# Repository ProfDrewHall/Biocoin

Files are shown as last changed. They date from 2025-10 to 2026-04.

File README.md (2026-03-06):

# Biocoin Platform

Biocoin is a modular wearable electrochemical sensing platform that integrates custom electronics, embedded firmware, and host-side software for multi-analyte detection in biofluids such as sweat and interstitial fluid.

Developed by the [BioEE Group](https://bioee.ucsd.edu) at the University of California, San Diego, Biocoin combines multimodal biosignal acquisition with wireless communication, microfluidic interfacing, and open analytical tools.

---

## Repository Overview

This repository contains the design assets for the Biocoin platform across hardware, firmware, software, and mechanical fixtures.

| Folder | Description |
|:---|:---|
| [`firmware/`](firmware/) | PlatformIO-based firmware for the nRF52840 controller and AD5940 analog front-end, including BLE control and data streaming. |
| [`software/`](software/) | Python host software for BLE communication, technique execution, logging, and result export. |
| [`PCB/`](PCB/) | PCB schematics, layouts, Gerbers, assembly files, and shared component libraries. |
| [`fixtures/`](fixtures/) | Mechanical design assets, fabrication exports, and fixture models for assembly and validation. |

---

## Architecture

The Biocoin system is organized as:

```text
Host software (Python CLI/package in software/)
  -> BLE GATT protocol
  -> nRF52840 firmware (firmware/)
     - SensorManager and technique implementations
     - AD5940 driver and board support
     - BLE, power, battery, and storage modules
  -> AD5940 analog front-end
  -> Electrochemical cell and integrated sensors
```

The current firmware structure is consistent with a FreeRTOS-based design using `SensorManager`, technique-specific sensor modules, and BLE streaming tasks.

---

## Supported Techniques

| Technique | Description | Output |
|:---|:---|:---|
| **CA** | Chronoamperometry | Current vs. time |
| **CV** | Cyclic Voltammetry | Current vs. voltage |
| **DPV** | Differential Pulse Voltammetry | Peak current vs. potential |
| **SWV** | Square-Wave Voltammetry | Differential current vs. potential |
| **IMP / EIS** | Impedance spectroscopy | Magnitude and phase |
| **OCP** | Open-circuit potential | WE potential vs. RE |
| **TEMP** | Temperature monitoring | Voltage-derived temperature data |
| **IONTOPH** | Iontophoretic stimulation | Current control and monitoring |

Each technique can be configured from the host and controlled over BLE. Data-producing techniques stream results back to the host software.

---

## Development Requirements

### Firmware

- [PlatformIO](https://platformio.org/) for build and flash workflows
- A supported nRF52840 board configuration for the Biocoin hardware
- Optional DFU tooling such as Nordic `nrfutil`

### Software

- Python 3.13 or newer
- Recommended: [`uv`](https://docs.astral.sh/uv/) for environment and dependency management
- Python dependencies defined in [`software/pyproject.toml`](software/pyproject.toml):
  - `bleak`
  - `colorama`
  - `numpy`

### Hardware and Mechanical

- Altium Designer or another tool capable of reviewing the PCB source/export files
- CAD software such as SolidWorks or FreeCAD for fixture review and export

---

## Typical Workflow

1. Build and flash the firmware in [`firmware/`](firmware/).
2. Use the Python tooling in [`software/`](software/) to connect over BLE.
3. Run a supported electrochemical technique and collect results.
4. Review or update board and fixture assets in [`PCB/`](PCB/) and [`fixtures/`](fixtures/).

---

## Example Directory Layout

```text
Biocoin/
|-- firmware/   # Embedded firmware, docs, scripts, and tests
|-- software/   # Python package, CLI runners, tests, logs, and results
|-- PCB/        # Board designs, Gerbers, assembly outputs, libraries
`-- fixtures/   # Mechanical assets and fabrication files
```

---

## Licensing

This repository contains both software and hardware design assets. Unless otherwise noted:

- [`firmware/`](firmware/) and [`software/`](software/) are provided under the MIT License.
- [`PCB/`](PCB/) and [`fixtures/`](fixtures/) are provided under the CERN-OHL-W v2.0 license.

See the top-level [`LICENSE`](LICENSE) file for the repository-level license notice.

---

## Authors and Maintainers

**BioEE Group, University of California, San Diego**

Principal Investigator: [Prof. Drew A. Hall](https://bioee.ucsd.edu)

Contributors:

- Risab Sankar
- Tyler Hack
- Members of the BioEE Group (UCSD ECE)

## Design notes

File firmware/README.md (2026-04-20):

# Biocoin Firmware

Firmware for the Biocoin wearable electrochemical platform.
This code runs on an nRF52840-based board and controls an Analog Devices AD5940 for multi-modal electrochemical sensing. It exposes a BLE interface for configuring techniques, starting/stopping tests, and streaming results to a host (Python app, mobile, etc.).

Current release: **v1.1.5**

> Techniques supported: **CA**, **CV**, **DPV**, **SWV**, **Impedance (EIS)**, **OCP**, **TEMP**, and **Iontophoresis**.

## v1.1.5 Highlights

- Improved BLE status reporting for malformed sensor control and parameter writes.
- Cleared stale error states after successful same-technique parameter updates.
- Made active-sensor cleanup failures preserve the active sensor and publish `ERROR` instead of masking failures as `NOT_RUNNING`.

---

## Features

- Modular sensor stack (`sensors/core` + `sensors/techniques`) with a common `Sensor` base class
- AD5940 HAL integration (clock/FIFO/LPDAC/LPAMP/DFT/sequencer, RTIA calibration) - based on ADI code
- Low-power operation with wakeup timer & sleep
- BLE data streaming and status updates
- Typed parameter blocks with bounds checks where applicable
- Lock-free byte streaming of results (float payloads)

---

## Getting Started

### Prerequisites
- [PlatformIO](https://platformio.org/) (VS Code extension or CLI)
- Note: If you are building on a linux-based platform, you'll need to install the udev rules (https://docs.platformio.org/en/latest/core/installation/udev-rules.html)
- Board: Biocoin board based on nRF52840
- Tooling for DFU (optional): Nordic `nrfutil`

### Build
From VS Code (PlatformIO) or CLI:
```bash
pio run
```

Note: `DEBUG_MODE` builds briefly block at startup while waiting for a USB serial connection to attach. The current timeout is about 2 seconds; after that, startup continues normally even if no serial monitor is connected.

Optional pre-push hook (runs sanity checks + mode smoke checks, builds `debug` + `release`, and copies artifacts to `build/<env>/`):
```bash
git config core.hooksPath .githooks
```

On Linux/macOS:
```bash
chmod +x .githooks/pre-push
```

On Windows (PowerShell), no `chmod` step is required.

### Flash
USB (default PlatformIO upload target):
```bash
pio run -t upload
```

DFU (example with `nrfutil`, adjust paths/softdevice/bootloader as needed):
```bash
# Example only - adapt to your bootloader/DFU flow
nrfutil dfu usb-serial -pkg firmware_dfu.zip -p <COM_PORT> -b 115200
```

---

## Repository Structure (high level)

```
src/
  main.cpp
  HWConfig/
    constants.h         # Aggregates build checks + config + pins
    build_checks.h      # Compile-time environment validation
    config.h            # Firmware/version/runtime constants
    pins.h              # Board pin assignments
  variants/biocoin/
    variant.h
    variant.cpp
  sensors/
    core/
      sensor.{h,cpp}
      sensor_manager.{h,cpp}
      datamover_task.{h,cpp}
    techniques/
      sequence_constants.h
      ca/echem_ca.{h,cpp}
      cv/echem_cv.{h,cpp}
      dpv/echem_dpv.{h,cpp}
      swv/echem_swv.{h,cpp}
      imp/echem_imp.{h,cpp}
      ocp/echem_ocp.{h,cpp}
      temp/echem_temp.{h,cpp}
      iontophoresis/iontophoresis.{h,cpp}
  bluetooth/
    bluetooth.{h,cpp}
    gatt.{h,cpp}
    transmitdata_task.h
    transmitdata_task.cpp
  battery/
    battery.{h,cpp}
    battery_task.{h,cpp}
  power/
    power.{h,cpp}
    led_task.{h,cpp}
  storage/
    storage.{h,cpp}
  drivers/
    ad5940_hal.{h,cpp}
    ad5940_helper.{h,cpp}
  util/
    debug_log.h
    task_sync.h
    util.{h,cpp}
```

---

## Architecture

All techniques inherit from `sensor::Sensor` and (for streaming) use `SensorQueue<T>` to push typed samples. `SensorManager` owns the active technique and mediates:

- `loadParameters(uint8_t* data, uint16_t len)`
- `start()` / `stop()`
- `ISR()` (invoked via AFE interrupt / data mover task)

**Data streaming:** techniques push `float` samples; the BLE TX pipeline sends a raw byte vector (little-endian floats) produced by `SensorQueue<T>::popBytes()`.

---

## SDK

This project now uses a repo-local PlatformIO variant in `src/variants/biocoin` (configured in `platformio.ini`) so board pin mapping/build settings are version-controlled with firmware source.
No manual edits to PlatformIO package files are required.
For lowest-power operation, SDK-level `WInterrupts` changes are still required (see `SDK Modifications/WInterrupts-port.c` and `SDK Modifications/WInterrupts-port.h`).

---

## Documentation

- `docs/README.md` - docs index and navigation
- `docs/BLE_PROTOCOL.md` - protocol and payload reference
- `docs/BUILD_FLASH.md` - build/flash environment notes
- `docs/BATTERY_CALIBRATION.md` - BLE logging + fit workflow for battery percent calibration constants
- `docs/POWER.md` - low-power behavior and SDK patch requirements
- `docs/RELEASE_CHECKLIST.md` - release prep checklist
- `test/README.md` - targeted parser/state transition test plan and vectors

---

## BLE Protocol (summary)

- A **Parameters** characteristic accepts a binary payload:
  - Byte `0`: `sensor::SensorType` (technique selector)
  - Bytes `1..N`: packed parameter struct for that technique (see below)
- A **Control** characteristic accepts a command (`START` / `STOP`)
- A **Status** characteristic reports `TestState` (`NOT_RUNNING`, `RUNNING`, `ERROR`, etc.)
- A **Data** characteristic streams measurement results as raw bytes (floats)
- TX transport detail: outgoing BLE data uses a bounded FreeRTOS stream buffer. If producers outrun BLE notify throughput, excess bytes are dropped and logged.

> UUIDs/handles are defined in the BLE layer (see `src/bluetooth/gatt.*`). Host apps should send the correct packed struct for the selected technique.

---

## Parameter Payloads (packed)

Below are the **packed** C layouts (host must match layout, types, and units). Each write to the Parameters characteristic must begin with the technique selector byte (`sensor::SensorType`) followed by the corresponding struct bytes.

### Chronoamperometry (CA)
```c++
struct CA_PARAMETERS {
  float  samplingInterval;    // [s]
  float  processingInterval;  // [s]
  float  maxCurrent;          // [uA] range hint
  float  pulsePotential;      // [mV] WE-RE pulse amplitude
  uint8_t channel;            // 0..3 (board mux)
} __attribute__((packed));
```

### Cyclic Voltammetry (CV)
```c++
struct CV_PARAMETERS {
  float  processingInterval;  // [s]
  float  maxCurrent;          // [uA] range hint
  float  Estart;              // [mV]
  float  Evertex1;            // [mV]
  float  Evertex2;            // [mV]
  float  Estep;               // [mV] step between DAC codes
  float  pulseWidth;          // [ms]
  uint8_t channel;            // 0..3
} __attribute__((packed));
```

### Differential Pulse Voltammetry (DPV)
```c++
struct DPV_PARAMETERS {
  float  processingInterval;  // [s]
  float  maxCurrent;          // [uA] range hint
  float  Estart;              // [mV]
  float  Estop;               // [mV]
  float  Epulse;              // [mV] pulse height
  float  Estep;               // [mV] ramp step
  float  pulseWidth;          // [ms]
  float  pulsePeriod;         // [ms]
  uint8_t channel;            // 0..3
} __attribute__((packed));
```

### Square Wave Voltammetry (SWV)
```c++
struct SWV_PARAMETERS {
  float  processingInterval;  // [s]
  float  maxCurrent;          // [uA] range hint
  float  Estart;              // [mV]
  float  Estop;               // [mV]
  float  Eamplitude;          // [mV] square-wave amplitude
  float  Estep;               // [mV] staircase step
  float  pulsePeriod;         // [ms]
  uint8_t channel;            // 0..3
} __attribute__((packed));
```

### Impedance / EIS (IMP)
```c++
struct IMP_PARAMETERS {
  float  samplingInterval;    // [s]
  float  processingInterval;  // [s]
  uint8_t IMP_4wire;          // 1=4-wire, 0=2-wire
  uint8_t AC_coupled;         // 1=AC, 0=DC
  float  maxCurrent;          // [uA] range hint
  float  Eac;                 // [mV] AC excitation
  float  frequency;           // [Hz]
} __attribute__((packed));
```

### Open Circuit Potential (OCP)
```c++
struct OCP_PARAMETERS {
  float  samplingInterval;    // [s]
  float  processingInterval;  // [s]
  uint8_t channel;            // board/AFE mux (see note)
} __attribute__((packed));
```

### Temperature Monitor (TEMP)
```c++
struct TEMP_PARAMETERS {
  float  samplingInterval;    // [s]
  float  processingInterval;  // [s]
  uint8_t channel;            // ADCMUXP_* selection (board dependent)
} __attribute__((packed));
```

### Iontophoresis
```c++
struct IONTOPHORESIS_PARAMETERS {
  float  samplingInterval;    // [s] monitor interval
  float  stimCurrent;         // [uA] commanded
  float  maxCurrent;          // [uA] safety threshold
} __attribute__((packed));
```

> **Channels:** `channel` maps to board-level MUX/AD5940 inputs (e.g., `ADCMUXP_*`). Keep host-side enums in sync with the firmware build for your hardware variant.

---

## Running a Technique (host flow)

1. **Select technique**: Write `SensorType` + packed struct to the **Parameters** characteristic.
2. **Start**: Write `START` to **Control**.
3. **Stream**: Subscribe to **Data** notifications (float samples as little-endian bytes).
4. **Stop**: Write `STOP` to **Control**.
5. **Status**: Read/subscribe to **Status** (`NOT_RUNNING`, `RUNNING`, `ERROR`, etc.).

---

## Implementation Notes

- AD5940 reference voltage should match your measured value (see configs in each technique).
- RTIA selection/auto-cal: Some techniques call `AD5940_CalibrateRTIA` unless external RTIA is forced.
- Power: Firmware disables SPI / enters sleep when possible to reduce current.
- Data types:
  - **Current** streams are in **µA** (computed from ADC code, PGA gain, Vref, and RTIA).
  - **Voltage** streams (e.g., OCP, TEMP) are in **mV**.
- Byte order: little-endian for all streamed floats.

---

## Troubleshooting

- **No data**: Ensure `processingInterval >= samplingInterval` (where applicable).
- **Invalid parameters**: Firmware replies via **Status** (`INVALID_PARAMETERS`) if struct size or values are off.
- **Out of range currents**: Pick appropriate `maxCurrent` so the code selects a safe RTIA/gain.
- **MTU**: For larger throughput, request higher ATT MTU on the central (typical 185-247+ depending on OS).

---

## ToDo List
Near term:
- Implement the current range for CA
- Implement advanced parameters
- Add comments / file headers / Readme.MD
- Add static_assert to check config constants
- Cleanup / refactor / reorganize code

Long term:
- Add other techniques: EIS, NPV, LSV, etc.
- Add CRC to parameters for BLE comm?
- Add a serial # to the BLE characteristics

---

## License

MIT

---

## Authors

**Drew A. Hall**
University of California, San Diego
Contact: drewhall@ucsd.edu

**Risab Sankar**
University of California, San Diego
Contact: rsankar@ucsd.edu

**Tyler Hack**
University of California, San Diego
Contact: thack@ucsd.edu

---

### Acknowledgments
Thanks to the BioEE group at UC San Diego and collaborators for contributions and testing.

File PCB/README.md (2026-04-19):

# PCB Design Files

This directory contains the PCB design deliverables for the BioCoin hardware, including source design files, fabrication outputs, assembly files, and shared Altium libraries.

## Folder Overview

### `Biocoin/`

PCB files for the BioCoin board.

- `design/`: Altium project files, PCB layout, schematics, harness files, and output job definitions
- `gerber/`: fabrication outputs for board manufacturing
- `assembly/`: bill of materials and pick-and-place files for assembly
- `Schematic.PDF`: exported schematic reference

Notable files:

- `design/Biocoin_v1.3.PrjPcb`
- `design/Biocoin_v1.3.PcbDoc`
- `assembly/BOM_Final_Biocoin_v1.3_AVDD=3.0V.xlsx`
- `assembly/BOM_Final_Biocoin_v1.3_AVDD=3.6V.xlsx`
- `assembly/Pick_and_Place_Assembly_Biocoin_v1.3.txt`

### `Docking Station/`

PCB files for the BioCoin docking station / motherboard.

- `design/`: Altium project files, PCB layout, schematics, and output job definitions
- `gerber/`: fabrication outputs for board manufacturing
- `assembly/`: bill of materials and pick-and-place files for assembly
- `Schematic.PDF`: exported schematic reference

Notable files:

- `design/Biocoin_Motherboard_v1.0.PrjPcb`
- `design/Biocoin_Motherboard.PcbDoc`
- `assembly/BOM_Final_DockingStation_v1.0.xlsx`
- `assembly/Pick_and_Place_Assembly_DockingStation_v1.0.txt`

### `Shared Libraries/`

Reusable Altium schematic and PCB libraries shared across the designs in this folder.

- `Modules.SchLib`
- `Modules.PcbLib`
- `Schlib.SchLib`
- `PcbLib.PcbLib`

## Manufacturing And Assembly Notes

For each board:

- Use the files in `gerber/` for PCB fabrication
- Use the files in `assembly/` for population and placement
- Use the `design/` folder if you need to open or modify the board in Altium Designer
- Use `Schematic.PDF` for quick review without opening the design tools

## Click-To-Order Links

### Biocoin

- [Order 10 sets](https://pcbminions.com/product/product_1773404171-10sets)
- [Order 100 sets](https://pcbminions.com/product/product_1773404171-100sets)

### Docking Station

- [Order 10 sets](https://pcbminions.com/product/product_1773677769-10sets)
- [Order 100 sets](https://pcbminions.com/product/product_1773677769-100sets)

## Tooling

These files are in Altium Designer format (`.PrjPcb`, `.PcbDoc`, `.SchDoc`, `.OutJob`, `.SchLib`, `.PcbLib`).

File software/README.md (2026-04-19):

# Biocoin Device Software

This repository contains Python code to interface with the Biocoin hardware platform over BLE.
It supports configuration and execution of all currently implemented techniques:

- Chronoamperometry (CA)
- Cyclic Voltammetry (CV)
- Differential Pulse Voltammetry (DPV)
- Square-Wave Voltammetry (SWV)
- Impedance (IMP)
- Open-Circuit Potential (OCP)
- Temperature Monitoring (TEMP)
- Iontophoresis (IONTOPH)

The software is organized as:

- a reusable backend library in `src/biocoin/`
- a Streamlit GUI package in `src/biocoin_gui/`
- standalone technique runner scripts in `src/run_*.py`

---

## Setup

The software requires Python 3.13 or newer. The backend uses Python 3.13 generic class syntax, so Streamlit must also run from a Python 3.13+ environment.

### 1. Clone the repository

```bash
git clone https://github.com/ProfDrewHall/Biocoin.git
cd Biocoin/software
```

### 2. Install Python 3.13

macOS with Homebrew:

```bash
brew install python@3.13
```

Confirm the installed version:

```bash
python3.13 --version
```

### 3. Create and activate a virtual environment

From the `software` directory:

```bash
python3.13 -m venv .venv
source .venv/bin/activate
python -m pip install --upgrade pip
```

After activation, `python --version` should report Python 3.13 or newer.

### 4. Install the package and dependencies

```bash
python -m pip install -e .
```

### 5. Run a technique script

Example:

```bash
python src/run_CA.py --help
```

### 6. Run the Streamlit GUI

```bash
python -m streamlit run src/biocoin_gui/app.py
```

Use `python -m streamlit` instead of `streamlit` so the GUI runs with the active Python 3.13 virtual environment.

If you are using `uv`, run:

```bash
uv run --python 3.13 streamlit run src/biocoin_gui/app.py
```

### Optional: Use `uv`

If you prefer `uv`, install it first:

```bash
brew install uv
```

Then run the GUI with Python 3.13:

```bash
uv run --python 3.13 streamlit run src/biocoin_gui/app.py
```

---

## Technique Runner Scripts

Each technique has a dedicated CLI script that exposes its parameters:

```bash
python src/run_CA.py --help
python src/run_CV.py --help
python src/run_DPV.py --help
python src/run_SWV.py --help
python src/run_IMP.py --help
python src/run_OCP.py --help
python src/run_TEMP.py --help
python src/run_IONTO.py --help
```

Typical output CSV paths default to `./results/*_output.csv` for data-producing techniques.

---

## Technique Lifecycle Contract

General flow:

1. `await technique.configure(...)`
2. `data = await technique.run(...)`
3. Consume `data` as a NumPy array

Returned shape expectations:

- Timed techniques (`CA`, `OCP`, `TEMP`, `IMP`) can return a variable number of samples based on BLE/runtime timing.
- Sweep techniques (`CV`, `DPV`, `SWV`) are expected to return deterministic point counts from their configured vectors.
- `Iontophoresis` does not stream samples and returns an empty `(0, 2)` array.

---

## Directory Layout

```text
src/
|-- run_CA.py
|-- run_CV.py
|-- run_DPV.py
|-- run_SWV.py
|-- run_IMP.py
|-- run_OCP.py
|-- run_TEMP.py
|-- run_IONTO.py
|-- biocoin/
|   |-- __init__.py
|   |-- device.py
|   |-- errors.py
|   |-- techniques/
|   |   |-- __init__.py
|   |   |-- base_technique.py
|   |   |-- ca.py
|   |   |-- cv.py
|   |   |-- dpv.py
|   |   |-- swv.py
|   |   |-- impedance.py
|   |   |-- ocp.py
|   |   |-- temp.py
|   |   |-- iontophoresis.py
|   |   |-- pulse_voltammetry.py
|   |   `-- validation.py
|   `-- utils/
|       `-- ble_util.py
|-- biocoin_gui/
|   |-- __init__.py
|   |-- app.py
|   |-- runtime.py
|   `-- pages/
|       |-- __init__.py
|       |-- ca.py
|       |-- cv.py
|       |-- dpv.py
|       |-- imp.py
|       |-- ip.py
|       |-- ocp.py
|       |-- swv.py
|       `-- temp.py
`-- utils/
    `-- logging_util.py
```

---

## License

MIT License

---

## Authors

**Drew A. Hall**
University of California, San Diego
Contact: drewhall@ucsd.edu

**Risab Sankar**
University of California, San Diego
Contact: rsankar@ucsd.edu

**Tyler Hack**
University of California, San Diego
Contact: thack@ucsd.edu

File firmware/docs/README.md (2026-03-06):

# Documentation Index

- `BLE_PROTOCOL.md`: BLE characteristics, command framing, and payload notes.
- `BUILD_FLASH.md`: Build/flash notes and environment assumptions.
- `BATTERY_CALIBRATION.md`: BLE logging, curve fitting, and config update workflow for battery percent calibration.
- `CA_TECHNIQUE.md`: CA-specific parameter constraints, timing behavior, and ENDSEQ handling.
- `CV_TECHNIQUE.md`: CV parameter constraints, wakeup timing guards, and ENDSEQ behavior.
- `DPV_TECHNIQUE.md`: DPV parameter constraints, pulse timing guards, and ENDSEQ behavior.
- `SWV_TECHNIQUE.md`: SWV parameter constraints, timing guards, and ENDSEQ behavior.
- `OCP_TECHNIQUE.md`: OCP channel/rate constraints, wakeup guards, and ENDSEQ behavior.
- `TEMP_TECHNIQUE.md`: Temperature channel/rate constraints, wakeup guards, and ENDSEQ behavior.
- `IMP_TECHNIQUE.md`: Impedance parameter constraints, wakeup guards, and ISR behavior.
- `IONTOPHORESIS_TECHNIQUE.md`: Iontophoresis parameter and runtime safety behavior.
- `CONTRIBUTING.md`: Coding, naming, and documentation conventions for firmware changes.
- `POWER.md`: Low-power behavior and required SDK `WInterrupts` patch context.
- `RELEASE_CHECKLIST.md`: Pre-release checklist for firmware updates.

## Known Issues / Limitations

- Lowest-power operation still depends on SDK-level `WInterrupts` modifications (`SDK Modifications/WInterrupts-port.c` and `SDK Modifications/WInterrupts-port.h`).
- Build warning gating excludes vendor code warnings (for example, `src/drivers/ad5940.c`); project code warnings are expected to stay clean.
- BLE TX uses a bounded stream buffer; if producer throughput exceeds notify throughput, some bytes may be dropped (logged as warnings).

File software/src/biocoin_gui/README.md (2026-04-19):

# Biocoin GUI

Streamlit-based graphical interface for the Biocoin control software.

## Layout

- `app.py`: Main Streamlit entrypoint and navigation setup.
- `runtime.py`: Shared GUI helpers for session state, background experiment execution, and exports.
- `pages/`: Technique-specific experiment pages.

## Running The GUI

From the repository root:

```bash
uv run --python 3.13 streamlit run src/biocoin_gui/app.py
```

## TODO

- Periodically check that the device connection is still active and update the GUI state when it drops.
- Block other experiments from starting until the current experiment is complete.

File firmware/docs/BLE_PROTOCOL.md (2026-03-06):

# BLE Protocol Notes

## Characteristics

- Parameters: binary payload (`SensorType` + packed parameter struct bytes).
- Control: single-byte command (`START`, `STOP`).
- Status: single-byte `TestState`.
- Data: raw little-endian float stream.

### Debug-only Characteristics (`DEBUG_MODE` builds only)

- Debug Battery Voltage: UUID `00001526-1212-EFDE-1523-785FEABC93AA`
  - Properties: `READ`, `NOTIFY`
  - Payload: 2-byte unsigned little-endian battery voltage in millivolts (`uint16`)
  - Example: payload `0xD2 0x0E` => `3794 mV`

## Payload Compatibility Rules

- Control writes must be exactly 1 byte.
- Parameters writes must be between 1 byte and the current BLE payload max (`MTU - ATT header`).
- Device name writes must be between 1 byte and `BLE_GAP_DEVNAME_MAX_LEN - 1`.
- Invalid payload length or null payload is ignored by firmware and logged as a warning.
- Host implementations should treat ignored writes as protocol errors and retry only with corrected payloads.

## TX Path Behavior

- Outgoing data is buffered in a bounded FreeRTOS stream buffer.
- Data is chunked to current negotiated MTU payload size.
- If producers outrun notify throughput, bytes can be dropped and a warning is logged.

## Host Guidance

- Always subscribe to Data before issuing `START`.
- Validate returned status transitions when changing techniques.
- Keep host-side struct packing and enum values in lock-step with firmware.

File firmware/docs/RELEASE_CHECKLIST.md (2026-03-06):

# Release Checklist

## Minimum Acceptance (must pass)

- [ ] `.githooks/pre-push` passes locally (sanity checks + mode smoke checks + `debug`/`release` builds + artifact copy).
- [ ] BLE smoke path passes at least once per release build: connect -> write parameters -> `START` -> data notify -> `STOP`.
- [ ] Battery reporting and device-name write/read behavior verified on hardware.
- [ ] Sleep/idle spot-check confirms no obvious high-power regression.

## Versioning and Notes

- [ ] Update firmware version in `src/HWConfig/config.h`.
- [ ] Update `REVISION_HISTORY.md` with release title/date and key changes.
- [ ] Verify `README.md` reflects current technique support and file layout.
- [ ] Verify version string is consistent across `README.md`, `REVISION_HISTORY.md`, and the intended git tag (for example, `v1.1.0`).

## Build and Validation

- [ ] Run `sh scripts/sanity_checks.sh`.
- [ ] Run `sh scripts/smoke_sensor_modes.sh`.
- [ ] Build firmware (`pio run -e debug` and `pio run -e release`).
- [ ] Flash and smoke test BLE connect/start/stop/data path.
- [ ] Verify battery reporting and device-name update behavior.
- [ ] Confirm no unintended high-power regressions.

## Repository Hygiene

- [ ] Ensure no temporary logs/artifacts are tracked.
- [ ] Confirm renamed/moved files are reflected in docs.
- [ ] Review release delta for unexpected files: `git diff --stat <last-tag>..HEAD`.
- [ ] Review full release commit list: `git log --oneline <last-tag>..HEAD`.
- [ ] Tag release commit after validation.

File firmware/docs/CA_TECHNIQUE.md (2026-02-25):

# Chronoamperometry (CA) Notes

This note captures CA-specific runtime constraints and behavior so the same rules can be applied to other electrochemistry techniques.

## Host Parameter Constraints

- Payload layout (`CAParameterPayload`) is fixed-size packed data (`17` bytes).
- `samplingInterval` and `processingInterval` must be finite and greater than `0`.
- `processingInterval` must be greater than or equal to `samplingInterval`.
- `channel` must be in range `[0, 3]`.
- `pulsePotential` must remain within bias limits derived from current `Vzero`:
  - `minBias = AD5940_MIN_DAC_OUTPUT - Vzero`
  - `maxBias = AD5940_MAX_DAC_OUTPUT - Vzero`

## FIFO Threshold Behavior

- FIFO threshold is computed as:
  - `round(processingInterval / samplingInterval)`
- Threshold is clamped to:
  - minimum: `kCAMinFifoThreshold`
  - maximum: `kCAMaxFifoThreshold`

## Wakeup Timer Behavior

- CA builds wakeup timer config from measured `LFOSCFreq` and configured sampling interval.
- Wake period uses:
  - `kCAWuptSleepTicks`
  - `kCAWuptWakeSubtractTicks`
- Start fails with cleanup if computed wake ticks are non-finite or too small.

## ENDSEQ Handling

- ISR drains FIFO on both `DATAFIFOTHRESH` and `ENDSEQ`.
- On `ENDSEQ`, CA stops the technique and publishes:
  - `NOT_RUNNING` on successful stop
  - `ERROR` if stop fails

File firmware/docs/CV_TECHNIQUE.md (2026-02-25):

# Cyclic Voltammetry (CV) Notes

## Host Parameter Constraints

- Payload layout (`CVParameterPayload`) is fixed-size packed data (`29` bytes).
- `processingInterval` and `pulseWidth` must be finite and greater than `0`.
- `Estep` must be non-zero.
- `channel` must be in range `[0, 3]`.
- Voltage points (`Estart`, `Evertex1`, `Evertex2`) must remain inside DAC headroom derived from `VzeroStart`.

## FIFO Threshold Behavior

- FIFO threshold is computed as `round(processingInterval * 1000 / pulseWidth)`.
- Threshold is clamped to `[1, 1023]`.

## Wakeup Timer Behavior

- Wakeup timer settings are validated before start.
- Start fails if computed wake/sleep ticks are non-finite or too small after timing offsets.

## Runtime Behavior

- Start has centralized failure cleanup (`cleanupStartFailure`) to guarantee SPI/peripheral shutdown.
- ISR drains FIFO for both `DATAFIFOTHRESH` and `ENDSEQ` events.
- On `ENDSEQ`, CV stops and publishes `NOT_RUNNING` (or `ERROR` if stop fails).

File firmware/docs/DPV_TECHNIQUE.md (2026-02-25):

# Differential Pulse Voltammetry (DPV) Notes

## Host Parameter Constraints

- Payload layout (`DPVParameterPayload`) is fixed-size packed data (`33` bytes).
- `processingInterval`, `pulseWidth`, and `pulsePeriod` must be finite and greater than `0`.
- `pulsePeriod` must be greater than or equal to `pulseWidth`.
- `Estep` must be non-zero.
- `channel` must be in range `[0, 3]`.
- Voltage points (`Estart`, `Estop`, `Epulse`) must remain inside DAC headroom derived from `VzeroStart`.

## FIFO Threshold Behavior

- FIFO threshold is computed as `round(processingInterval * 1000 / pulseWidth)`.
- Threshold is clamped to `[1, 1023]`.

## Wakeup Timer Behavior

- High/low pulse timing ticks are validated before start.
- Start fails if any computed wakeup ticks are non-finite or too small after timing offsets.

## Runtime Behavior

- Start has centralized failure cleanup (`cleanupStartFailure`) to guarantee SPI/peripheral shutdown.
- ISR drains FIFO for both `DATAFIFOTHRESH` and `ENDSEQ` events.
- On `ENDSEQ`, DPV stops and publishes `NOT_RUNNING` (or `ERROR` if stop fails).

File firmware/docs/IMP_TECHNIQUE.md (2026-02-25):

# Impedance (IMP/EIS) Notes

## Host Parameter Constraints

- Payload layout (`IMPParameterPayload`) is fixed-size packed data (`22` bytes).
- `samplingInterval`, `processingInterval`, `frequency`, and `Eac` must be finite and greater than `0`.
- `processingInterval` must be greater than or equal to `samplingInterval`.
- Boolean flag fields (`IMP_4wire`, `AC_coupled`) must be `0` or `1`.

## FIFO Threshold Behavior

- FIFO threshold is computed from interval ratio and rounded down to a multiple of `4` samples.
- Minimum threshold is `4`.

## Wakeup Timer Behavior

- Wakeup ticks are validated before start.
- Start fails if ticks are non-finite or too small for configured wake/sleep offsets.

## Runtime Behavior

- Start has centralized failure cleanup (`cleanupStartFailure`) to guarantee SPI/peripheral shutdown.
- ISR drains FIFO for both `DATAFIFOTHRESH` and `ENDSEQ` events.
- On `ENDSEQ`, IMP stops and publishes `NOT_RUNNING` (or `ERROR` if stop fails).

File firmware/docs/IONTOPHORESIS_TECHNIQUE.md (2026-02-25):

# Iontophoresis Notes

## Host Parameter Constraints

- Payload layout (`IontophoresisParameterPayload`) is fixed-size packed data (`12` bytes).
- `samplingInterval` and `maxCurrent` must be finite and greater than `0`.
- `stimCurrent` must be finite, greater than or equal to `0`, and less than or equal to `maxCurrent`.

## Runtime Behavior

- Start has centralized failure cleanup (`cleanupStartFailure`) to guarantee SPI/peripheral shutdown.
- Stimulation safety is enforced in the monitoring task by comparing measured current against `maxCurrent`.
- On safety overcurrent, iontophoresis stops and publishes `CURRENT_LIMIT_EXCEEDED`.

## Timing Note

- This technique does not use AD5940 wakeup timer sequencing for sample cadence.
- Sampling cadence is controlled by the FreeRTOS monitoring task delay.

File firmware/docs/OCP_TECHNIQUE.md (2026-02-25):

# Open Circuit Potential (OCP) Notes

## Host Parameter Constraints

- Payload layout (`OCPParameterPayload`) is fixed-size packed data (`9` bytes).
- `samplingInterval` and `processingInterval` must be finite and greater than `0`.
- `processingInterval` must be greater than or equal to `samplingInterval`.
- `channel` must be one of the allowed OCP mux channels.

## FIFO Threshold Behavior

- FIFO threshold is computed as `round(processingInterval / samplingInterval)`.
- Threshold is clamped to `[1, 1023]`.

## Wakeup Timer Behavior

- Wakeup ticks are validated before start.
- Start fails if ticks are non-finite or too small for configured wake/sleep offsets.

## Runtime Behavior

- Start has centralized failure cleanup (`cleanupStartFailure`) to guarantee SPI/peripheral shutdown.
- ISR drains FIFO for both `DATAFIFOTHRESH` and `ENDSEQ` events.
- On `ENDSEQ`, OCP stops and publishes `NOT_RUNNING` (or `ERROR` if stop fails).

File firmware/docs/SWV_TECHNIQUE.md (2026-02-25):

# Square Wave Voltammetry (SWV) Notes

## Host Parameter Constraints

- Payload layout (`SWVParameterPayload`) is fixed-size packed data (`29` bytes).
- `processingInterval` and `pulsePeriod` must be finite and greater than `0`.
- `Estep` must be non-zero.
- `channel` must be in range `[0, 3]`.
- Voltage points (`Estart`, `Estop`, `Eamplitude`) must remain inside DAC headroom derived from `VzeroStart`.

## FIFO Threshold Behavior

- FIFO threshold is computed as `round(processingInterval * 1000 / (pulsePeriod / 2))`.
- Threshold is clamped to `[1, 1023]`.

## Wakeup Timer Behavior

- Sample-delay and pulse-width timing ticks are validated before start.
- Start fails if computed ticks are non-finite or too small after timing offsets.

## Runtime Behavior

- Start has centralized failure cleanup (`cleanupStartFailure`) to guarantee SPI/peripheral shutdown.
- ISR drains FIFO for both `DATAFIFOTHRESH` and `ENDSEQ` events.
- On `ENDSEQ`, SWV stops and publishes `NOT_RUNNING` (or `ERROR` if stop fails).

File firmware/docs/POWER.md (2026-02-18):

# Power Notes

## Runtime Strategy

- Peripheral blocks are enabled only when needed for active measurements.
- Multiple input GPIOs are explicitly disconnected to minimize leakage.
- BLE TX uses bounded buffering to avoid unbounded memory growth.

## SDK Patch Requirement

- Lowest-power operation still requires SDK-level `WInterrupts` modifications.
- See:
  - `SDK Modifications/WInterrupts-port.c`
  - `SDK Modifications/WInterrupts-port.h`

## Validation Suggestions

- Measure current in idle advertising, connected idle, and active measurement modes.
- Re-check power after any pin-map or interrupt-path change.

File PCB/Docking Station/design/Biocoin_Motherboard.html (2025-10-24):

Reporting Options

# File in Newer Format

Date | : | 7/17/2022
Time | : | 7:33:55 PM
Project name | : | C:\Users\TEMP\Documents\PCB Projects\Biocoin_Motherboard\Biocoin_Motherboard.PrjPcb
Schematic documents | : | DIGITAL_DATA.SchDoc

Version | Warning
22.3.0 | Custom diff pair suffixes are not supported in this version.

These files were generated in a later version of Altium Designer. Be aware that some data may have been added through functionality not available in your current version and will therefore not be available to you.

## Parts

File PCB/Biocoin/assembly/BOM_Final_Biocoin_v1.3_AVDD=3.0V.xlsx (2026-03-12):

Manufacturer_Part_Number | Description | Designator | Quantity on PCB | Value | Do Not Install | Unit Price ($USD) (@ Quantity 10x) | Unit Price ($USD) (@ Quantity 100x) | Supplier
C0603X5R1E473K030BB | Multilayer Chip Capacitor 0201 | C38 | 1 | 47nF |  | 0.039 | 0.0227 | Digikey
C0603X5R1E104K030BB | Multilayer Chip Capacitor 0201 | C37 | 1 | 100nF |  | 0.043 | 0.0253 | Digikey
C0201C104K9PAC7867 | Multilayer Chip Capacitor 0201 | C3, C4, C6, C12, C13, C17, C21, C27, C32, C33, C34, CLPF1 | 12 | 100nF |  | 0.045 | 0.0263 | Digikey
C0603X5R1A474M030BC | Multilayer Chip Capacitor 0201 | C1, C7, C10, C14 | 4 | 470nF |  | 0.102 | 0.063 | Digikey
0201X105K6R3CT | Multilayer Chip Capacitor 0201 | C20, C29, C39 | 3 | 1uF |  | 0.105 | 0.105 | Digikey
GRM035R60J475ME15D | Multilayer Chip Capacitor 0201 | C2, C5,C8, C15, C18, C25, C26, C28, C30 | 9 | 4.7uF |  | 0.112 | 0.0701 | Digikey
C0402C333J4RACAUTO | Multilayer Chip Capacitor 0402 | CTIA1 | 1 | 33nF |  | 0.165 | 0.1174 | Digikey
GRT155R71H104KE01D | Multilayer Chip Capacitor 0402 | C9, C11 | 2 | 100nF |  | 0.029 | 0.0164 | Digikey
04026D226MAT2A | Multilayer Chip Capacitor 0402 | C16, C19, C24, C31 | 4 | 22uF |  | 0.315 | 0.2118 | Digikey
GRM188R61E106KA73J | Multilayer Chip Capacitor 0603 | C36 | 1 | 10uF |  | 0.142 | 0.09 | Digikey
GRM188R60J476ME15D | Multilayer Chip Capacitor 0603 | C22, C23 | 2 | 47uF |  | 0.088 | 0.088 | Digikey
N/A | Surface Mount Resistor 0201 | R5, R8, R28, R31 | 4 | N/A | DNI | 0 | 0
RMCF0201ZT0R00 | Surface Mount Resistor 0201 | R1, R12, R15, R16, R27 | 5 | 0Ω |  | 0.006 | 0.0048 | Digikey
RMCF0201ZT0R00 | Surface Mount Resistor 0201 | R19, R24, R29 | 3 | 0Ω | DNI | 0 | 0
RC0201FR-071KL | Surface Mount Resistor 0201 | R25 | 1 | 1Ω |  | 0.008 | 0.005 | Digikey
RMCF0201FT5K10 | Surface Mount Resistor 0201 | R11 | 1 | 5.1kΩ |  | 0.005 | 0.0048 | Digikey
RMCF0201FT10K0 | Surface Mount Resistor 0201 | R23 | 1 | 10kΩ |  | 0.01 | 0.007 | Digikey
RE0201BRE0710KL | Surface Mount Resistor 0201 | RCAL1 | 1 | 10kΩ |  | 0.234 | 0.1632 | Digikey
RMCF0201FT49K9 | Surface Mount Resistor 0201 | R4, R7, R21, R22 | 4 | 49.9kΩ |  | 0.007 | 0.0046 | Digikey
ERJ-1GNF1333C | Surface Mount Resistor 0201 | R14 | 1 | 133kΩ |  | 0.039 | 0.0202 | Digikey
RE0201BRE07100KL | Surface Mount Resistor 0201 | R9, R10 | 2 | 100kΩ |  | 0.199 | 0.1408 | Digikey
ERJ-1GNF1623C | Surface Mount Resistor 0201 | R6, R17 | 2 | 162kΩ |  | 0.039 | 0.0202 | Digikey
ERJ-1GNF3743C | Surface Mount Resistor 0201 | R20 | 1 | 374kΩ |  | 0.039 | 0.0202 | Digikey
CRCW02015M60FNED | Surface Mount Resistor 0201 | R18 | 1 | 5.6MΩ |  | 0.041 | 0.0209 | Digikey
ERJ-2GE0R00X | Surface Mount Resistor 0402 | R13 | 1 | 0Ω |  | 0.014 | 0.0087 | Digikey
ERJ-2RKF1000X | Surface Mount Resistor 0402 | R26 | 1 | 100Ω |  | 0.028 | 0.0138 | Digikey
RP73PF1E100RBTD | Surface Mount Resistor 0402 | RSENSE | 1 | 100Ω |  | 0.135 | 0.1124 | Digikey
CRCW04024M99FKED | Surface Mount Resistor 0402 | R3 | 1 | 4.99MΩ |  | 0.034 | 0.0176 | Digikey
RC0402FR-0710ML | Surface Mount Resistor 0402 | R2 | 1 | 10MΩ |  | 0.004 | 0.0032 | Digikey
RC0402FR-0710ML | Surface Mount Resistor 0402 | RTIA1 | 1 | 10MΩ | DNI | 0 | 0
MMZ0603S601HT000 | Surface Mount Ferrite 0201 | L2, L4 | 2 | - |  | 0.085 | 0.0593 | Digikey
DFE252012F-100M=P2 | Surface Mount Inductor | L1 | 1 | 10uH |  | 0.2 | 0.1645 | Digikey
DFE201612E-2R2M=P2 | Surface Mount Inductor | L3 | 1 | 2.2uH |  | 0.2 | 0.1645 | Digikey
APHHS1005LCGCK | Green LED 0402 | D1 | 1 | - |  | 0.194 | 0.1366 | Digikey
MAX17270ENE+T | Buck-Boost Converter | IC1 | 1 | - |  | 5.066 | 4.2687 | Digikey
OPA990IDCKR | Opamp | IC2 | 1 | - |  | 0.809 | 0.6459 | Digikey
MAX4372TEBT+T | Current Sense Amplifier | IC3 | 1 | - |  | 2.499 | 2.0641 | Digikey
MAX17291ANT+T | Boost Converter | IC6 | 1 | - |  | 2.069 | 1.6995 | Digikey
BM02B-ACHSS-GAN-TF(LF)(SN) | Connector Header Surface Mount | J1 | 1 | - |  | 0.419 | 0.3557 | Digikey
PMEG3010ER,115 | Diode Schottky | J2 | 1 | - |  | 0.228 | 0.1435 | Digikey
N/A, Exposed pads | Surface Mount Header Pin Pad | J3, J4 | 2 | - | DNI | 0 | 0
5034802000 | 20 Position FFC, FPC Connector | J5 | 1 | - |  | 1.404 | 1.1931 | Digikey
N/A, Exposed pads | Surface Mount Header Pin Pad | J7, J8 | 2 | - | DNI | 0 | 0
MDBT50Q-1MV2 | MDBT50Q_52840 | M2 | 1 | - |  | 6.15 | 6.15 | Digikey
CSD75208W1015 | -20-V, P channel NexFET | Q1 | 1 | - |  | 0.473 | 0.3053 | Digikey
DMP32D5SFB-7B | MOSFET (P-Channel) | Q2 | 1 | - |  | 0.277 | 0.175 | Digikey
DMN62D1LFB-7B | MOSFET (N-Channel) | Q3 | 1 | - |  | 0.215 | 0.1347 | Digikey
TF412ST5G | N-ch JFET Transistor | Q4 | 1 | - |  | 0.315 | 0.1998 | Digikey
NANOT100AS | Smallest Push Button Switch | S1 | 1 | - |  | 0.358 | 0.2993 | Digikey
AD5940BCBZ-RL | Electrochemical Front End | U1 | 1 | - |  | 10.66 | 9.4095 | Digikey
TLV8542RUGR | Low Input Bias Current Opamp | U2, U4 | 2 | - |  | 0.942 | 0.7556 | Digikey
TMUX1104DQAR | 4:1 Analog MUX | U3 | 1 | - |  | 2.189 | 1.8016 | Digikey
TPS7A0230PDQNR | Small Low Iq LDO | U6 | 1 | - |  | 0.536 | 0.4218 | Digikey
MAX44264EWT+T | Small Low Iq Opamp | U8 | 1 | - |  | 1.485 | 1.2077 | Digikey
 |  |  | Total Unit Price per PCB ($USD) @ Quantity 10x : |  |  | 43.13
 |  |  | Total Unit Price per PCB ($USD) @ Quantity 100x : |  |  | 36.26

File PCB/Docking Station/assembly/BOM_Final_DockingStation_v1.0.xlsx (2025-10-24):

Manufacturer_Part_Number | Description | Designator | Quantity | Value | Do Not Install
C0805C103J5RAC7025 | Multilayer Chip Capacitor 0805 | C3 | 1 | 10nF
08055C153KAT2A | Multilayer Chip Capacitor 0805 | C4 | 1 | 15nF
C0805C104K5RAC7800 | Multilayer Chip Capacitor 0805 | C13, C14 | 2 | 100nF
C0805F474K3RAC7800 | Multilayer Chip Capacitor 0805 | C5, C7, C8 | 3 | 470nF
C0805C106K9PAC7800 | Multilayer Chip Capacitor 0805 | C1, C2, C6, C9, C11, C12 | 6 | 10uF
N/A | Multilayer Chip Capacitor 0805 | C10 | 1 | N/A | DNI
RC0805JR-070RL | Surface Mount Resistor 0805 | R11 | 1 | 0Ω
311-470ARTR-ND | Surface Mount Resistor 0805 | R2 | 1 | 470Ω
RC0805FR-071KL | Surface Mount Resistor 0805 | R6, R9 | 2 | 1kΩ
RC0805FR-072KL | Surface Mount Resistor 0805 | R8 | 1 | 2kΩ
RC0805FR-0710KL | Surface Mount Resistor 0805 | R10, R13 | 2 | 10kΩ
RC0805FR-0720KL | Surface Mount Resistor 0805 | R3 | 1 | 20kΩ
RC0805JR-07100KL | Surface Mount Resistor 0805 | R5 | 1 | 100kΩ
RC0805FR-071ML | Surface Mount Resistor 0805 | R7, R12 | 2 | 1MΩ
RMCF0805FT10M0 | Surface Mount Resistor 0805 | R1 | 1 | 10MΩ
N/A | Surface Mount Resistor 0805 | R4, R14, R15, R16 | 4 | N/A | DNI
5988130107F | Surface Mount LED 0805 | D1 | 1 | -
N/A | Through-hole LED footprint | D2, D3, D4 | 3 | - | DNI
1050170001 | Conn Micro USB Type B RCP 5 | J1 | 1 | -
NRPN031PAEN-RC | Pin Header 3x1 | J2 | 1 | -
MBR120ESFT3G | Diode Schottky 1A Surface Mount | J3 | 1 | -
M20-9990246 | Pin Header 2x1 | J4, J5, J10, J12, J14, J15, J16, J19, J20, J21 | 10 | -
855-22-010-10-001101 | 10 pin POGO pin header | J6, J8 | 2 | -
SHF-105-01-L-D-SM | Surface Mount Shrouded Header | J7 | 1 | -
61300411121 | CONN HEADER VERT 4POS 2.54MM | J9 | 1 | - | DNI
855-22-008-10-001101 | 8 pin POGO pin header | J11, J13 | 2 | -
DS1020-03ST1D | 3 pin right angle SPE connector | J17, J18 | 2 | -
1725708 | Phoenix Screw Terminal Connector | J22, J23 | 2 | -
S2B-PH-K-S(LF)(SN) | LiPo Battery JST Connector | J* | 1 | -
BLM21BD222TN1D | Surface Mount Inductor 0805 | L1 | 1 | Ferrite Bead
DMG2305UX-13 | P-Channel MOSFET DMG2305UX-13 | M1, M2 | 2 | -
1101M2S3CQE2 | Slide Switch SPDT Through Hole | S1 | 1 | -
B3U-1000P | SWITCH TACTILE SPST-NO 0.05A 12V | S2 | 1 | - | DNI
N/A | Screw Hole | SC1, SC2, SC3, SC4 | 4 | - | DNI
5010 | PC TEST POINT MULTIPURPOSE RED | TP1 | 1 | -
5011 | PC TEST POINT MULTIPURPOSE BLACK | TP3 | 1 | -
MCP73831T-2ACI/OT | Charger IC Lithium Ion/Polymer | U1 | 1 | -
AP2171WG-7 | Do Not Install | U2 | 1 | - | DNI
SPN02SXCN-RC | Jumper for J2 Header | N/A | 1 | -

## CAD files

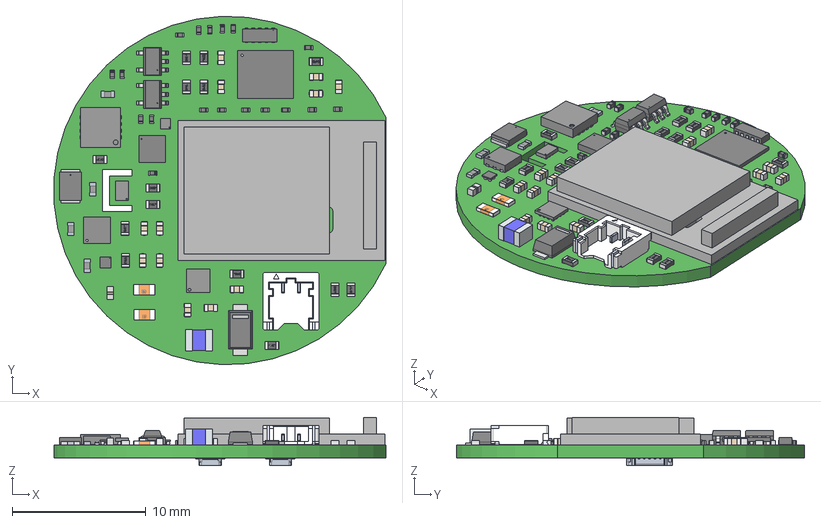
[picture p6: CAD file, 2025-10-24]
fixtures/assets/DPV_PCB_v2.step
24.9 x 26.1 x 3.60 mm
User_Library-0402R x 14
MDBT50Q_3D_Drawing_20180620_RGB8421504
SW3dPS-d0402h025 x 4
ThermalPin
PinsArrayLR
User_Library-SMD_Ceramic_Capacitors_0402_(1005)_BB x 12
PMDPB58UPE,115
SDO_SOD-123FL_ONS
Extruded
term1
term2
SW3dPS-0603_SMD_Capacitor x 2

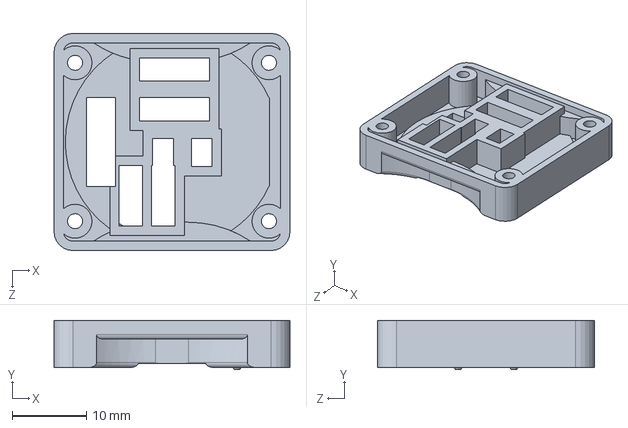
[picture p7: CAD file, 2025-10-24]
fixtures/design/Holder - rev 6.SLDPRT
31.8 x 6.65 x 29.2 mm

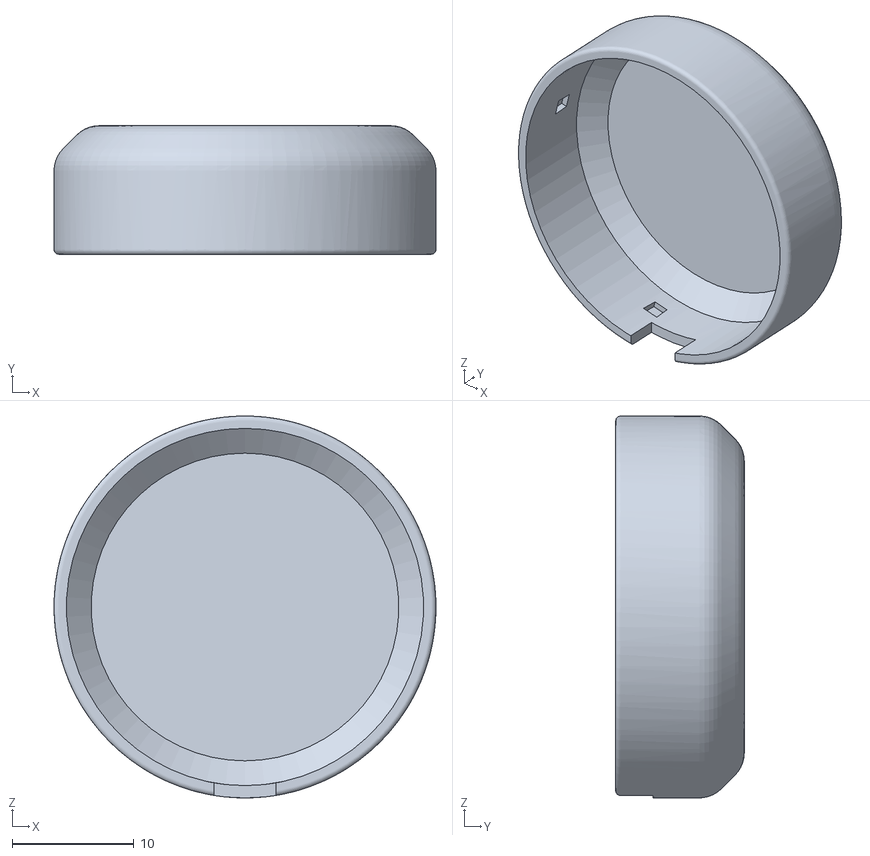
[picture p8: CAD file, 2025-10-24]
fixtures/design/Large Battery/Top - rev 1 - Big Battery.STL
31.3 x 10.5 x 31.3

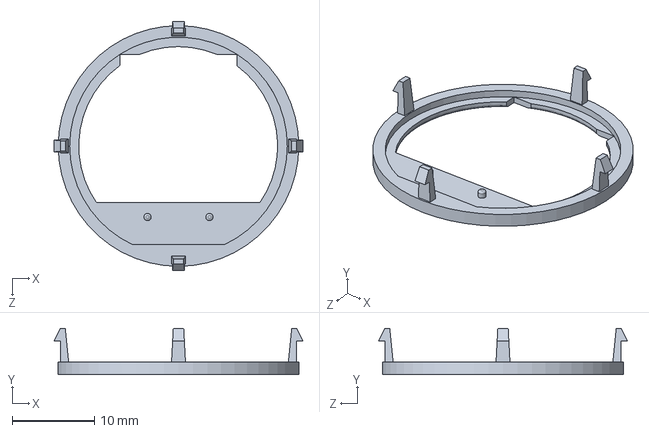
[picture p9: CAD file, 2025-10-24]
fixtures/design/Small Battery/Bottom - rev 2.SLDPRT
30.2 x 5.59 x 30.2 mm

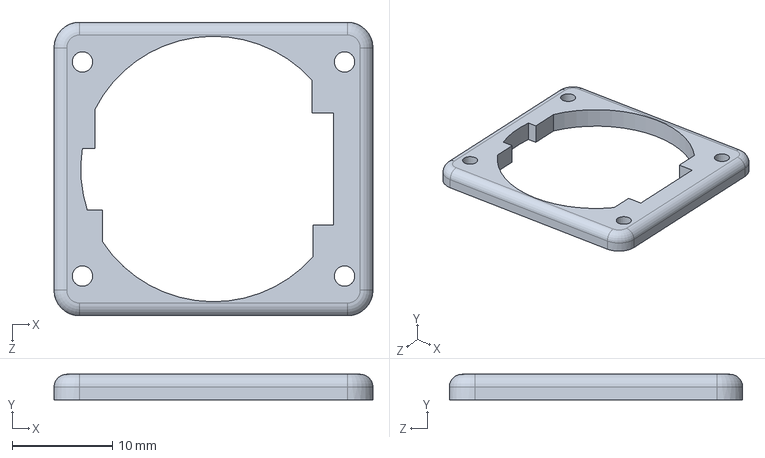
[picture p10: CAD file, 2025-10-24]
fixtures/design/Holder Top - rev 3.SLDPRT
31.8 x 2.54 x 29.2 mm

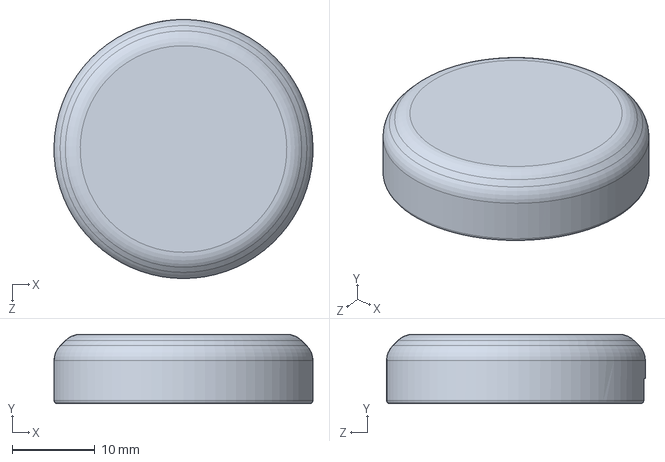
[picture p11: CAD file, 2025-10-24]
fixtures/design/Small Battery/Top - rev 1.SLDPRT
31.3 x 8.38 x 31.3 mm

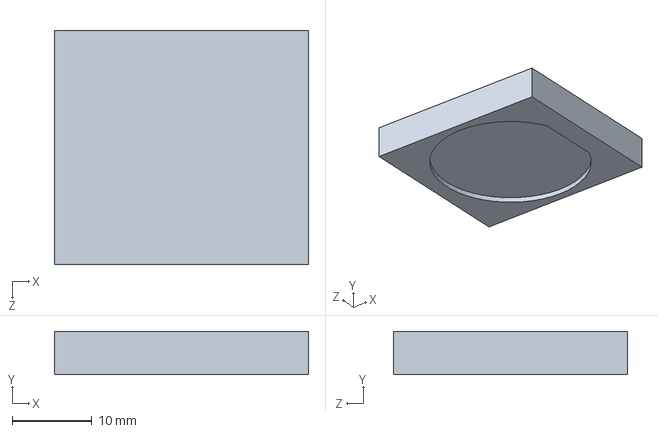
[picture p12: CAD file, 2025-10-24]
fixtures/design/Large Battery/Holder - rev 2.SLDPRT
31.8 x 5.42 x 29.2 mm

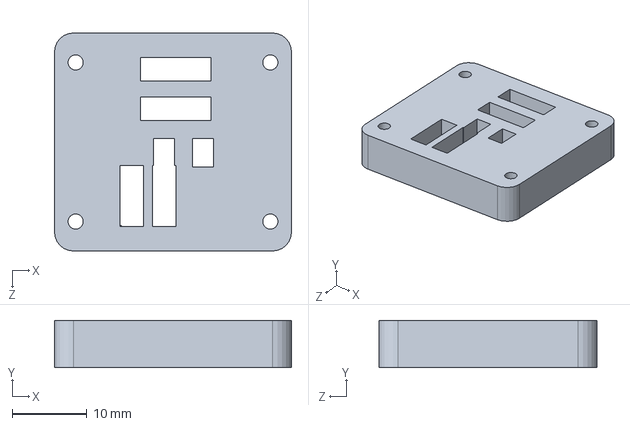
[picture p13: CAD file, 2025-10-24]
fixtures/design/Small Battery/Holder - rev 2.SLDPRT
31.8 x 6.35 x 29.2 mm

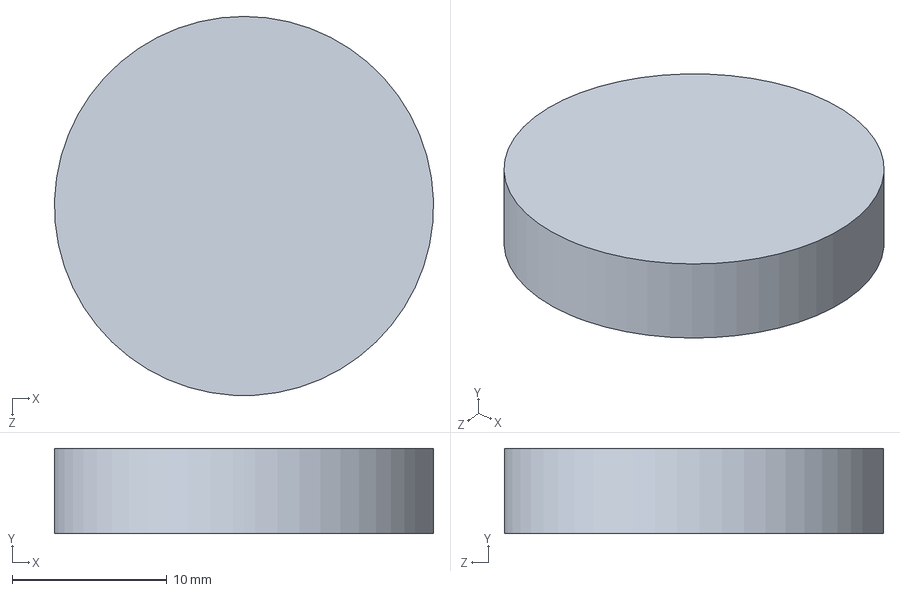
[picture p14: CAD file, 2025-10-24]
fixtures/design/Large Battery/Battery.SLDPRT
24.5 x 5.51 x 24.5 mm

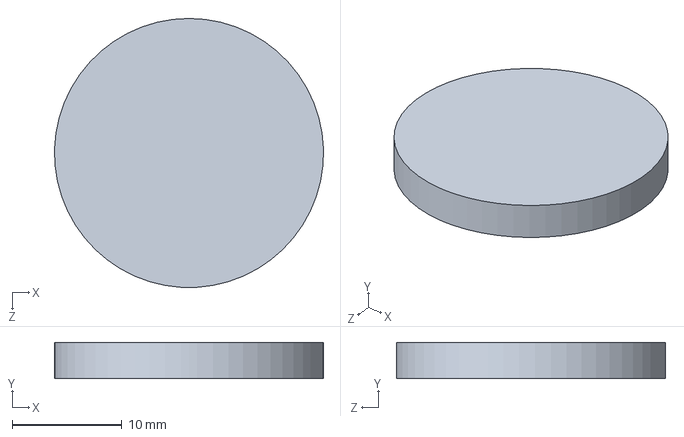
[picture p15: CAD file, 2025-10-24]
fixtures/design/Small Battery/Battery.SLDPRT
24.5 x 3.30 x 24.5 mm

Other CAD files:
fixtures/fabrication/Holder - rev 6.STL
fixtures/design/Large Battery/Bottom - rev 1.SLDPRT
fixtures/design/Large Battery/Bottom - rev 1 - Big Battery.STL
fixtures/design/Small Battery/Top - rev 1 - Small Battery.STL
fixtures/design/Large Battery/Top - rev 1.SLDPRT
fixtures/design/Small Battery/Bottom - rev 2.STL

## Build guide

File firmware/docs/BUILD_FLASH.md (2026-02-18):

# Build and Flash Notes

## Tooling

- PlatformIO (CLI or VS Code extension)
- nRF52840 target board

## Typical Commands

```bash
pio run
pio run -t upload
```

## Environment Assumptions

- Repo-local board variant is selected in `platformio.ini`.
- Build currently targets GNU++11 toolchain defaults for Adafruit nRF52 Arduino framework.

## Troubleshooting

- If command-line build tools are missing in shell, use PlatformIO from VS Code.
- If BLE/device name behavior seems stale after updates, verify the device rebooted after configuration writes.

## Rollback (Known-Good Firmware)

If validation fails after flashing a new build, roll back to a known-good tag/commit.

1. Find the known-good version:

```bash
git tag --list
git log --oneline --decorate --max-count=30
```

2. Checkout the known-good revision (example with tag):

```bash
git checkout v1.1.0
```

3. Rebuild and reflash:

```bash
pio run
pio run -t upload
```

4. Confirm basic health checks:
- BLE advertises and connects.
- Status characteristic reports expected transitions.
- Start/stop works for at least one technique.

5. Return to working branch after rollback testing:

```bash
git checkout main
```

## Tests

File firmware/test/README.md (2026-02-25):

# Targeted Test Plan

This repository currently uses hardware-in-loop validation.  
Use this plan to cover parser/state-transition regressions with focused host-driven tests.

## Hardware Setup (EChem Loopback)

- For EChem unit-test runs, connect a `10 kOhm` resistor between `RE0` and `WE0`.
- Short `CE0` to `RE0`.

## Parser Tests

- Invalid payload length for each technique parameter struct.
- Null/empty payload handling for control and parameter writes.
- Unknown `SensorType` and unknown `SensorCmd` rejection.

## State Transition Tests

- `NOT_RUNNING -> RUNNING -> NOT_RUNNING` for each technique.
- Technique switch while stopped (`A -> B`) updates active sensor cleanly.
- Invalid parameter write leaves system in `INVALID_PARAMETERS` without crash.

## BLE TX Path Tests

- Data notifications after `START` with subscriber enabled.
- Buffer pressure scenario: verify dropped-byte warning appears when host is slow.
- Repeated start/stop cycles do not deadlock TX/data mover tasks.

## Suggested Execution

- Drive GATT writes/notifications from a host script and assert expected status bytes.
- Capture serial debug logs in `DEBUG_MODE` for task lifecycle and drop warnings.

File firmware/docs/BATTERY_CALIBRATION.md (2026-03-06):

# Battery Calibration Workflow

This workflow captures battery discharge voltage data and fits a voltage-to-percent curve for firmware constants in `src/HWConfig/config.h`.

## Prerequisites

- Flash **debug** firmware (the raw battery-voltage BLE characteristic is debug-only).
- Python 3.10+.
- Script deps from `scripts/pyproject.toml`:
  - `bleak`
  - `numpy`
  - `scipy`
  - `matplotlib`

Example setup (from `firmware/`):

```bash
cd scripts
uv sync
```

or:

```bash
cd scripts
pip install bleak numpy scipy matplotlib
```

## 1) Log Battery Data Over BLE

Run the logger while the device discharges:

```bash
python log_battery_ble.py \
  --address <BLE_MAC_OR_ID> \
  --debug-voltage \
  --debug-voltage-char-uuid 00001526-1212-EFDE-1523-785FEABC93AA \
  --interval-sec 120 \
  --output battery_log.csv
```

Notes:

- `--debug-voltage-char-uuid` points to the debug-only raw battery voltage characteristic.
- `battery_log.csv` is generated locally and should not be committed.

## 2) Fit Curve and Generate Coefficients

```bash
python analyze_battery_curve.py \
  --input battery_log.csv \
  --fit both \
  --out-coeff battery_fit_coefficients.json \
  --out-fit-fig battery_fit_v_percent.png \
  --out-time-fig battery_voltage_vs_time.png
```

Generated artifacts:

- `battery_fit_coefficients.json`
- `battery_fit_v_percent.png`
- `battery_voltage_vs_time.png`

The PNG files are analysis artifacts and should not be committed.

## Artifact Format

`battery_fit_coefficients.json` contains:

- `fit_mode`
- `target_percent_source`
- `n_samples`
- `linear`: `{ a, b, rmse }` (if requested)
- `sigmoid`: `{ k, v0, rmse }` (if requested)

Firmware uses the sigmoid coefficients:

- `kBatteryFitSlope`  <= `sigmoid.k`
- `kBatteryFitMidVoltage` <= `sigmoid.v0`

## 3) Update Firmware Constants

Copy sigmoid values into `src/HWConfig/config.h`:

- `battery::kBatteryFitSlope`
- `battery::kBatteryFitMidVoltage`

Then rebuild and validate battery percentage behavior over a known discharge curve.

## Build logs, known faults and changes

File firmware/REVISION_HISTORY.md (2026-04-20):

# Revision History

## v1.1.5 - 2026-04-20
- Sensor status reliability:
  - Cleared stale `INVALID_PARAMETERS` / error states after successful same-technique parameter reloads.
  - Updated malformed BLE sensor control and parameter writes to publish `INVALID_PARAMETERS`.
  - Made active-sensor cleanup failures preserve the current sensor and publish `ERROR` instead of masking failed stops as `NOT_RUNNING`.
- Documentation updates:
  - Added a README note that `DEBUG_MODE` builds briefly wait for USB serial before continuing startup.

## v1.1.3 - 2026-03-06
- Added battery coefficients for FP10AAB36 battery
- Task lifecycle alignment:
  - Added full heartbeat LED task lifecycle control (`startHeartbeatTask` + `stopHeartbeatTask`) with cooperative notify-based shutdown in `src/power/led_task.cpp`.
- Battery API naming alignment:
  - Renamed battery APIs:
    - `readVoltage(...)` -> `readBatteryVoltageV(...)`
    - `readLevel(...)` -> `readBatteryPercent(...)`
    - `mapBatteryLevel(...)` -> `voltageToPercent(...)`
- BLE protocol/debug documentation:
  - Added debug-only battery-voltage characteristic details to `docs/BLE_PROTOCOL.md` (UUID `0x1526`, `uint16` little-endian mV payload).
- Repository alignment cleanup:
  - Standardized product naming to `Biocoin` across firmware/docs defaults/comments.
  - Fixed stale variant comment in `platformio.ini`.
  - Updated pre-push/release flow alignment so `.githooks/pre-push` runs sanity + smoke checks before `debug`/`release` builds and artifact sync.
  - Refreshed `scripts/smoke_sensor_modes.sh` paths for current `src/sensors/core` + `src/sensors/techniques/*` layout.
  - Expanded `.gitignore` hygiene for Python/test artifacts and local outputs (`__pycache__`, logs, CSV/PNG, temp, coverage) in both firmware scripts and `software/`.
- Battery calibration and model update:
  - Added BLE battery logging + analysis workflow docs and scripts (`docs/BATTERY_CALIBRATION.md`, `scripts/log_battery_ble.py`, `scripts/analyze_battery_curve.py`).
  - Updated battery sigmoid mapping constants in `src/HWConfig/config.h` from fitted calibration outputs.
- Debug BLE battery/AFE controls (debug builds only):
  - Added debug battery-voltage characteristic support and host refresh command handling.
  - Added debug AFE burn-load control characteristic (`0x1527`) for controlled discharge testing.
  - Added disconnect-time cleanup to ensure debug AFE burn mode is turned off.
- BLE logger robustness improvements:
  - Added full discovered-device/UUID scan printing mode (`--print-discovered`).
  - Added Windows-focused connection retry + uncached service discovery fallback handling.
  - Added graceful recovery/exit behavior for mid-session `Not connected` disconnects.
- Debug startup reliability:
  - Capped debug serial wait at startup so BLE advertising still starts without an attached serial monitor.

## v1.1.2 - 2026-02-25

- Technique refactor for reuse and clarity:
  - Added shared setup pipeline helpers in `src/sensors/techniques/setup_measurement_helpers.h`.
  - Added shared wakeup-tick math helpers in `src/sensors/techniques/technique_lifecycle_helpers.h`.
  - Added shared runtime interrupt/FIFO helpers in `src/sensors/techniques/technique_runtime_helpers.h`.
  - Added shared technique payload parse/log helpers in `src/sensors/techniques/parameter_io_helpers.h`.
- Sensor-runtime reliability fixes:
  - Restored post-RTIA-calibration re-arm flow (FIFO/interrupt/sequencer generator) in technique setup paths to avoid no-data runs.
  - Added a CA stop-path best-effort final FIFO drain to reduce dropped tail samples.
  - Updated data mover wake path to ISR-safe FreeRTOS APIs and synchronized stop signaling with an atomic flag.
- Validation and API cleanup:
  - Consolidated exact-struct payload parsing through `payload_validation` to remove duplicate parse logic.
  - Removed unused `processData()` declarations from technique headers since it is not part of the `Sensor` base interface.
- Documentation/test note updates:
  - Added unit-test hardware hookup note (10k resistor RE0-WE0, CE0 shorted to RE0) to test docs.
  - Added tracked pre-push hook at `.githooks/pre-push` to build `debug` and `release` and copy artifacts into `build/<env>/`.

## v1.1.1 - 2026-02-18

- Refactored BLE transmit pipeline:
  - Replaced misspelled `tansmitdata_task.cpp` with `transmitdata_task.cpp`.
  - Moved TX path to bounded stream-buffer flow with clearer task lifecycle handling.
- Hardened BLE/GATT payload validation:
  - Added centralized helper `src/util/payload_validation.h`.
  - Added/expanded length checks for control, parameters, and device-name writes.
  - Removed stale/dead GATT declaration from `src/bluetooth/gatt.h`.
- Sensor manager and task cleanup:
  - Improved active-sensor lifecycle handling and status update paths.
  - Updated sensor/data mover control flow for cleaner start/stop behavior.
- Source-level cleanup and consistency:
  - Removed redundant includes and `using namespace` remnants.
  - Normalized sensor/driver filenames to consistent lowercase snake_case and updated includes accordingly.
  - Applied line-ending normalization and formatting consistency updates across source files.
  - Fixed compile issues/warnings introduced during cleanup (missing include and signed/unsigned compare in impedance path).
- CI and automation additions:
  - Added `scripts/sanity_checks.sh` for include/path/style/line-ending checks.
  - Added `scripts/smoke_sensor_modes.sh` for sensor-mode coverage smoke checks.
  - Added `scripts/check_project_warnings.sh` to gate non-vendor compiler warnings.
  - Added GitHub Actions workflow `../.github/workflows/firmware-sanity.yml` to run checks in CI.
- Documentation expansion:
  - Added docs set: `docs/README.md`, `docs/BLE_PROTOCOL.md`, `docs/BUILD_FLASH.md`, `docs/POWER.md`,
    and `docs/RELEASE_CHECKLIST.md`.
  - Updated top-level `README.md` for current architecture, BLE TX behavior, and SDK low-power notes.
  - Added targeted host/HIL test plan in `test/README.md`.

## v1.1.0 (2026-02-17)

- Added **SWV (Square Wave Voltammetry)** support in firmware and documented SWV payloads.
- Refactored hardware configuration:
  - Split `src/HWConfig/constants.h` into `src/HWConfig/build_checks.h`, `src/HWConfig/config.h`, and `src/HWConfig/pins.h`.
  - Kept `src/HWConfig/constants.h` as the aggregator include.
- Migrated to repo-local variant configuration:
  - Added `src/variants/biocoin/variant.h` and `src/variants/biocoin/variant.cpp`.
  - Added local variant marker macro `BIOCOIN_LOCAL_VARIANT`.
  - Updated `platformio.ini` to use local variant (`board_build.variants_dir`, `board_build.variant`).
- Added compile-time environment checks for variant selection and board assumptions (LFRC/LFXO, QSPI, pin count).
- Hardened battery/BLE behavior:
  - Added cooperative task stop helper `src/util/task_sync.h`.
  - Updated `src/battery/battery_task.cpp` to use notify-based stop/wait and safer restart behavior.
  - Switched battery service updates from `blebas.write(...)` to `blebas.notify(...)`.
  - Added `bledis.setFirmwareRev(kFirmwareRev)` in `src/bluetooth/bluetooth.cpp`.
- Improved storage device-name handling:
  - Replaced hardcoded max name length with `BLE_GAP_DEVNAME_MAX_LEN + 1`.
  - Added defensive name clamping in `storage::writeDeviceName(...)`.
- Code quality cleanup:
  - Removed file-scope `using namespace ...` across `src/*.cpp` and applied explicit qualification.
  - Added module/API comments to updated headers and source files.
- Documentation updates:
  - Updated `README.md` for current project structure and SDK notes.
  - Added note that SDK `WInterrupts` modifications are still needed for lowest-power operation.

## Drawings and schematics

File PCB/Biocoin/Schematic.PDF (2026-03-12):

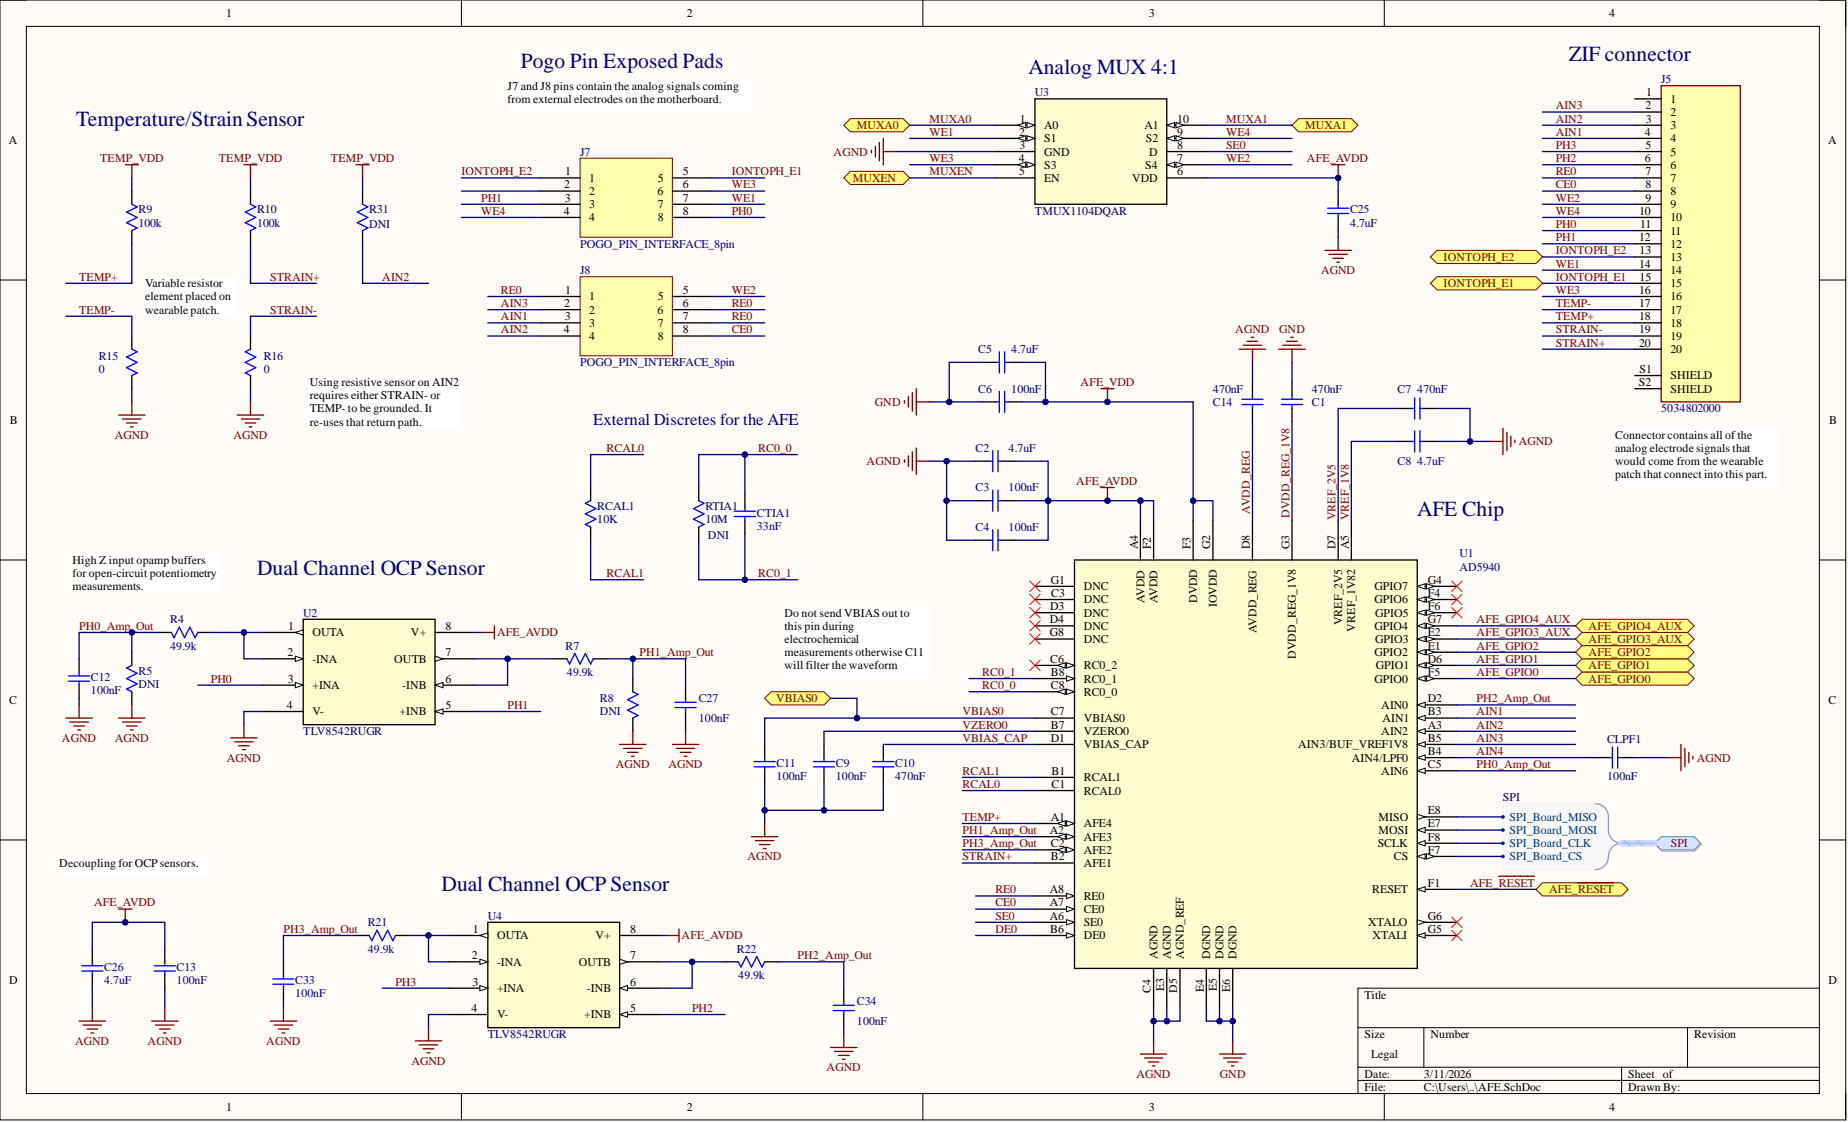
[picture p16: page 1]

Pogo Pin Exposed Pads

J7 and J8 pins contain the analog signals coming
from external electrodes on the motherboard.

Using resistive sensor on AIN2
requires either STRAIN- or
TEMP- to be grounded. It
re-uses that return path.

External Discretes for the AFE

Connector contains all of the
analog electrode signals that
would come from the wearable
patch that connect into this part.

High Z input opamp buffers
for open-circuit potentiometry
measurements.

Dual Channel OCP Sensor

Do not send VBIAS out to
this pin during
electrochemical
measurements otherwise C11
will filter the waveform

VZERO0 | VZERO0 B7
VBIAS_CAP | VBIAS_CAP D1

RCAL1 B1 RCAL0 C1 AFE4 A1 AFE3 A2 AFE2 C2 AFE1 B2

Decoupling for OCP sensors.

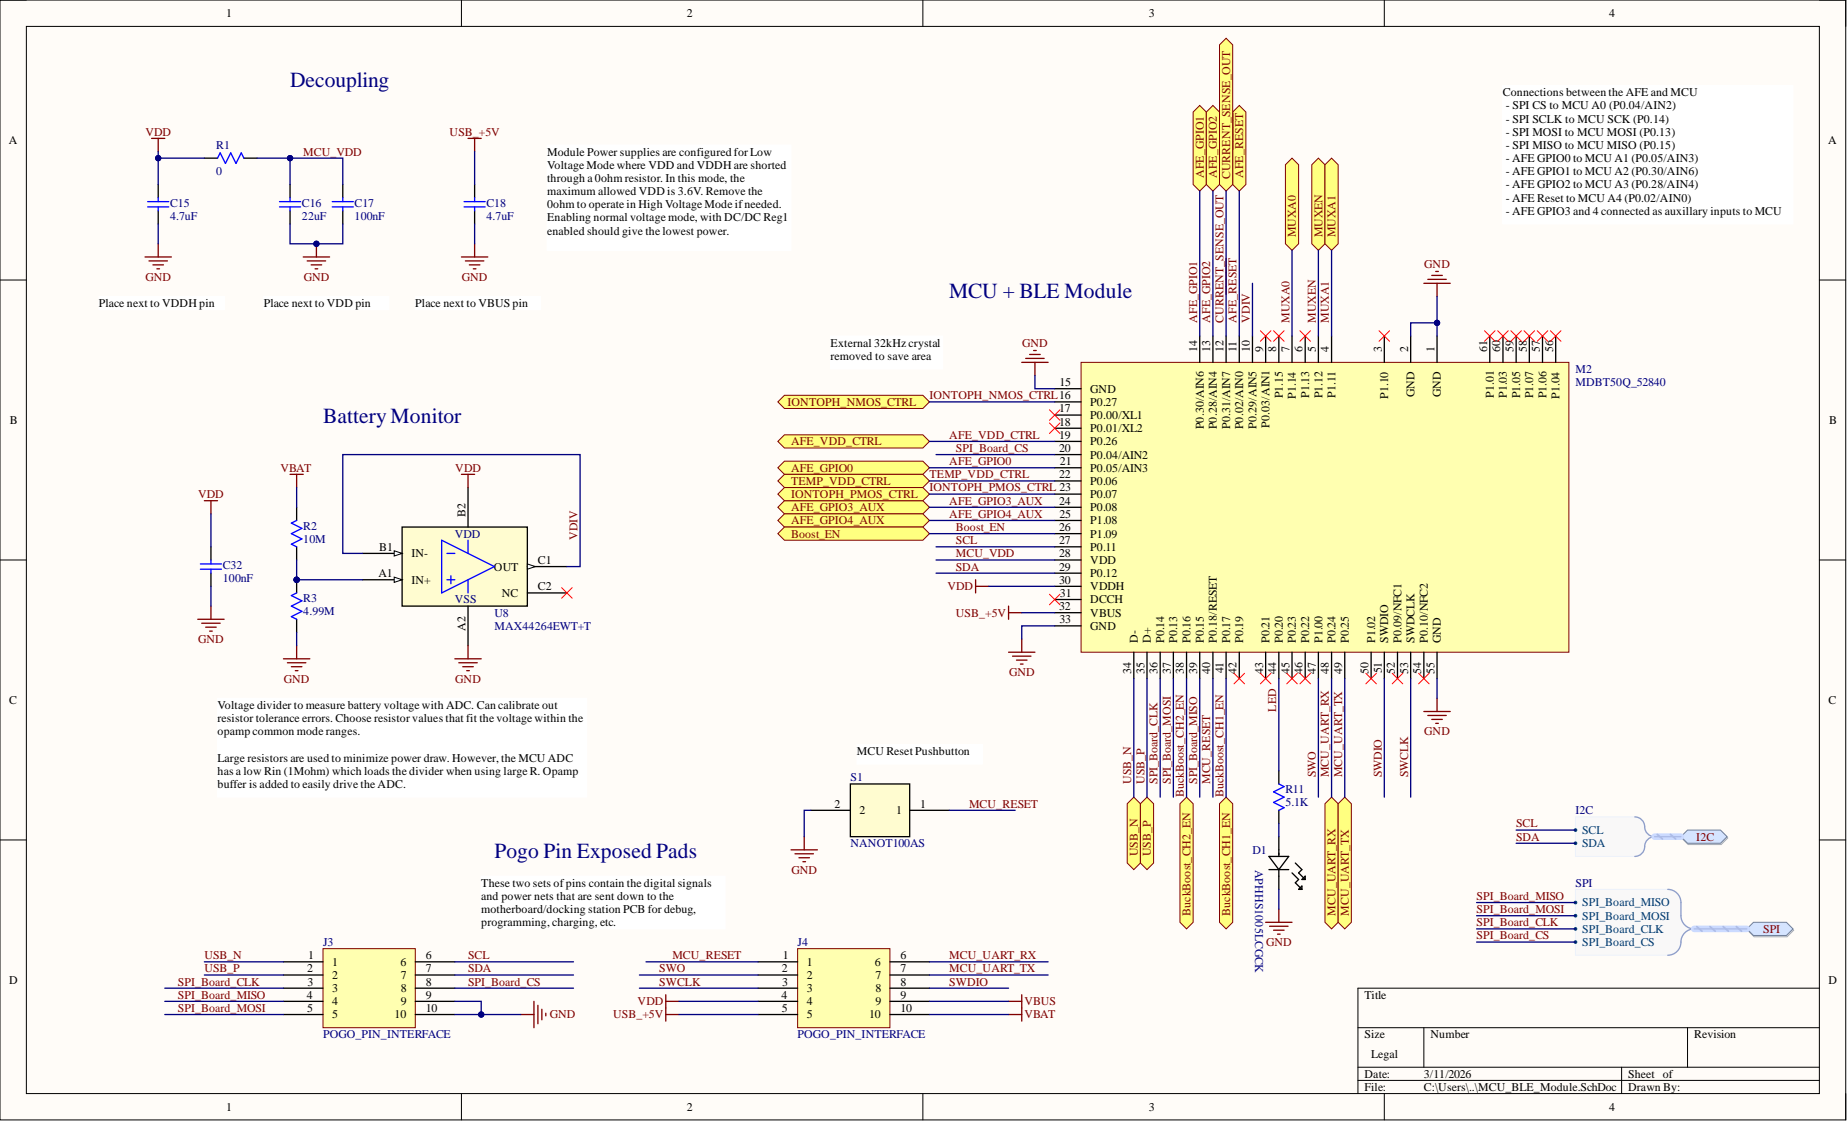
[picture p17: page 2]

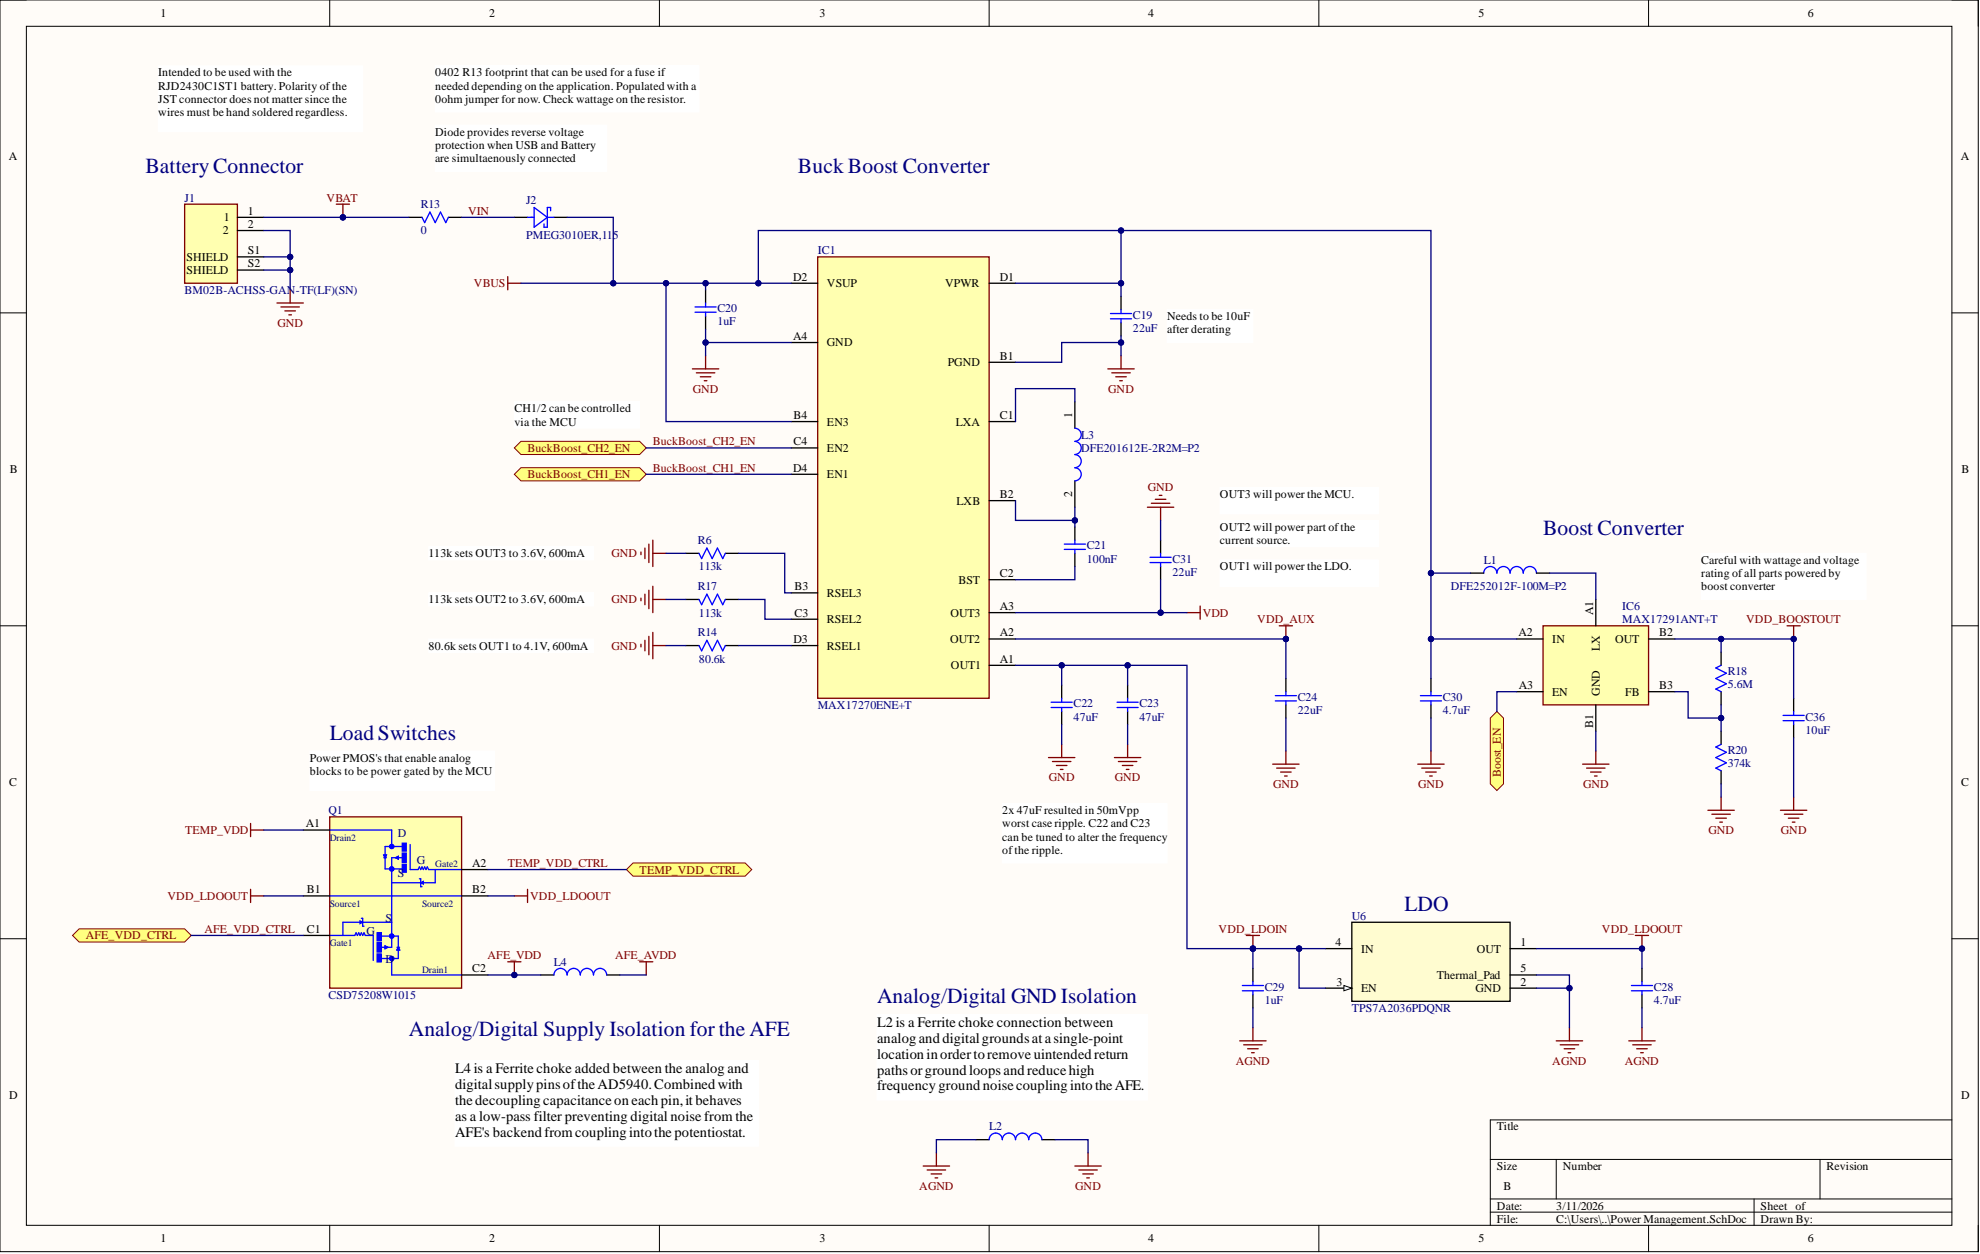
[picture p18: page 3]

Intended to be used with the
RJD2430C1ST1 battery. Polarity of the
JST connector does not matter since the
wires must be hand soldered regardless.

0402 R13 footprint that can be used for a fuse if
needed depending on the application. Populated with a
0ohm jumper for now. Check wattage on the resistor.

Diode provides reverse voltage
protection when USB and Battery
are simultaenously connected

BM02B-ACHSS-GAN-TF(LF)(SN)

OUT3 will power the MCU.

OUT2 will power part of the
current source.

OUT1 will power the LDO.

Careful with wattage and voltage
rating of all parts powered by
boost converter

Power PMOS'sthat enable analog
blocks to be power gated by the MCU

2x 47uF resulted in 50mVpp worst case ripple. C22 and C23 can be tuned to alter the frequency of the ripple.

Analog/Digital GND Isolation

L2 is a Ferrite choke connection between
analog and digital grounds at a single-point
location in order to remove uintended return
paths or ground loops and reduce high
frequency ground noise coupling into the AFE.

Analog/Digital Supply Isolation for the AFE

L4 is a Ferrite choke added between the analog and
digital supply pins of the AD5940. Combined with
the decoupling capacitance on each pin, it behaves
as a low-pass filter preventing digital noise from the
AFE's backend from coupling into the potentiostat.

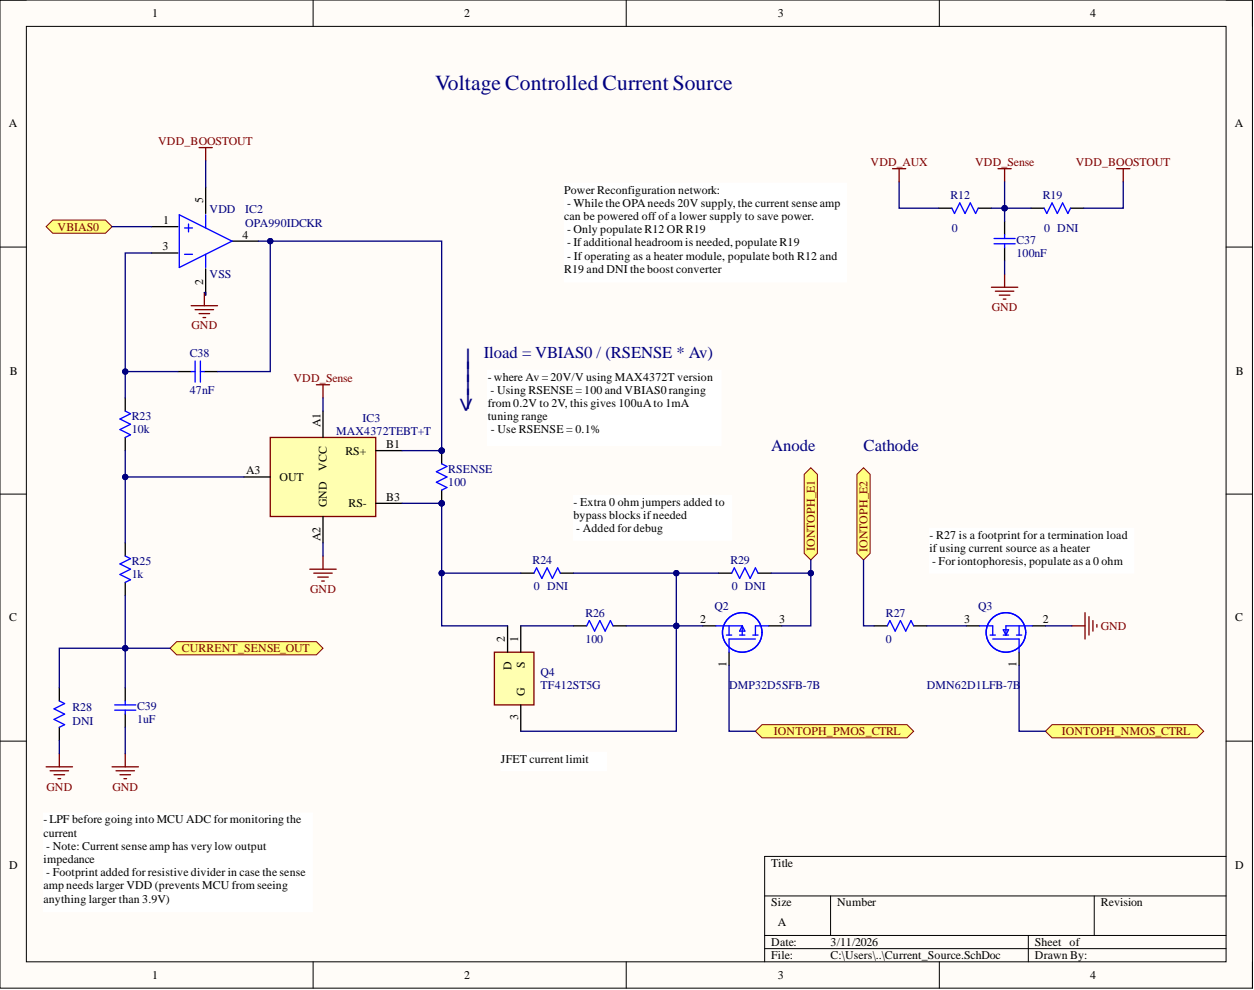
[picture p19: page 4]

Voltage Controlled Current Source

Power Reconfiguration network:
- While the OPA needs 20V supply, the current sense amp
can be powered off of a lower supply to save power.
- Only populate R12 OR R19
- If additional headroom is needed, populate R19
- If operating as a heater module, populate both R12 and
R19 and DNI the boost converter

Iload = VBIAS0 / (RSENSE * Av)
- where Av = 20V/V using MAX4372T version
- Using RSENSE = 100 and VBIAS0 ranging
from 0.2V to 2V, this gives 100uA to 1mA
tuning range
- Use RSENSE = 0.1%

- Extra 0 ohm jumpers added to
bypass blocks if needed

if using current source as a heater
- For iontophoresis, populate as a 0 ohm

- LPF before going into MCU ADC for monitoring the
current
- Note: Current sense amp has very low output
impedance
- Footprint added for resistive divider in case the sense
amp needs larger VDD (prevents MCU from seeing
anything larger than 3.9V)

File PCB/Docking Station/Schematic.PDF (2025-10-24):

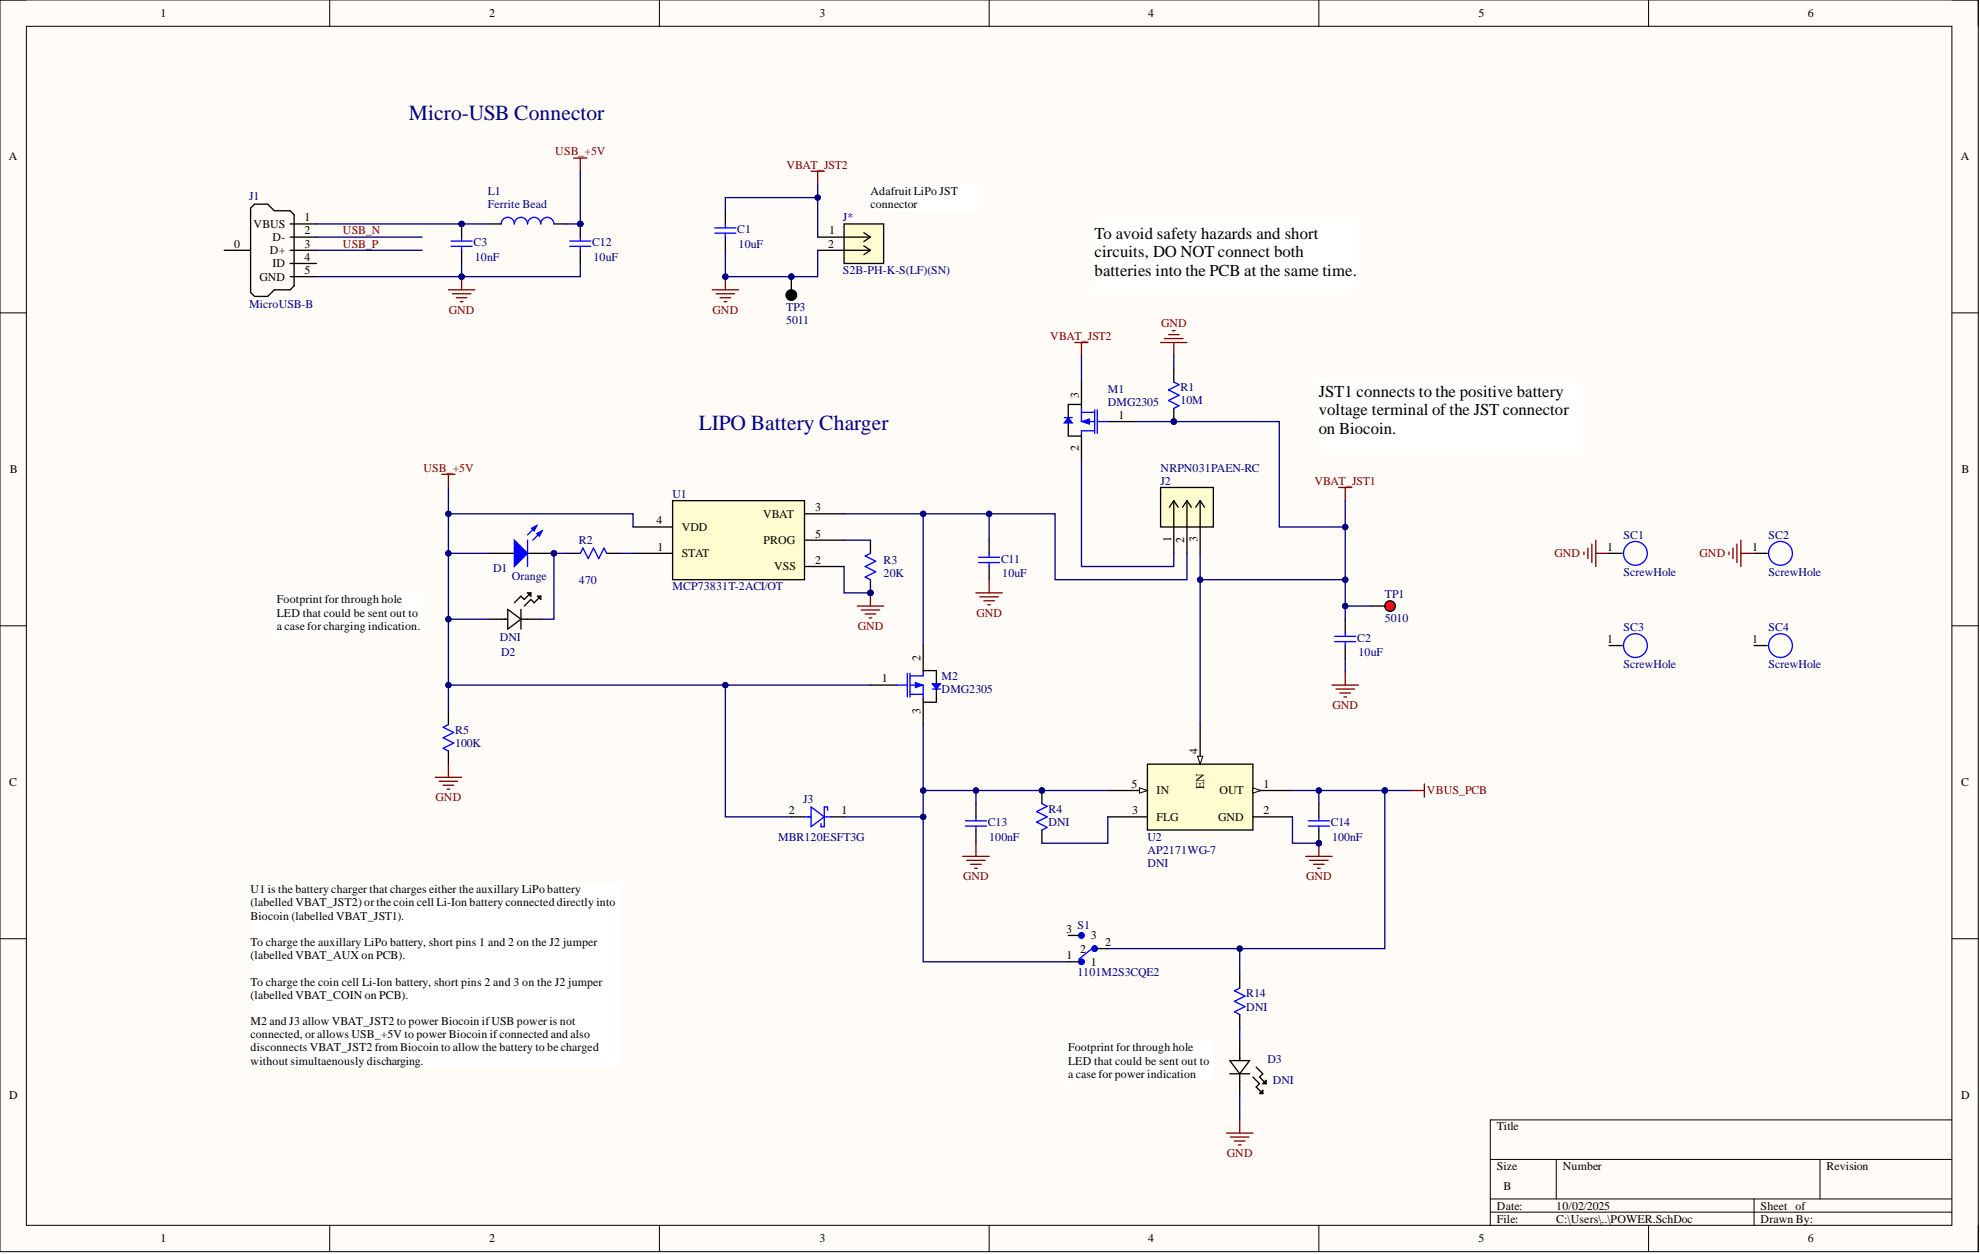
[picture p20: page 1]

To avoid safety hazards and short
circui
bat

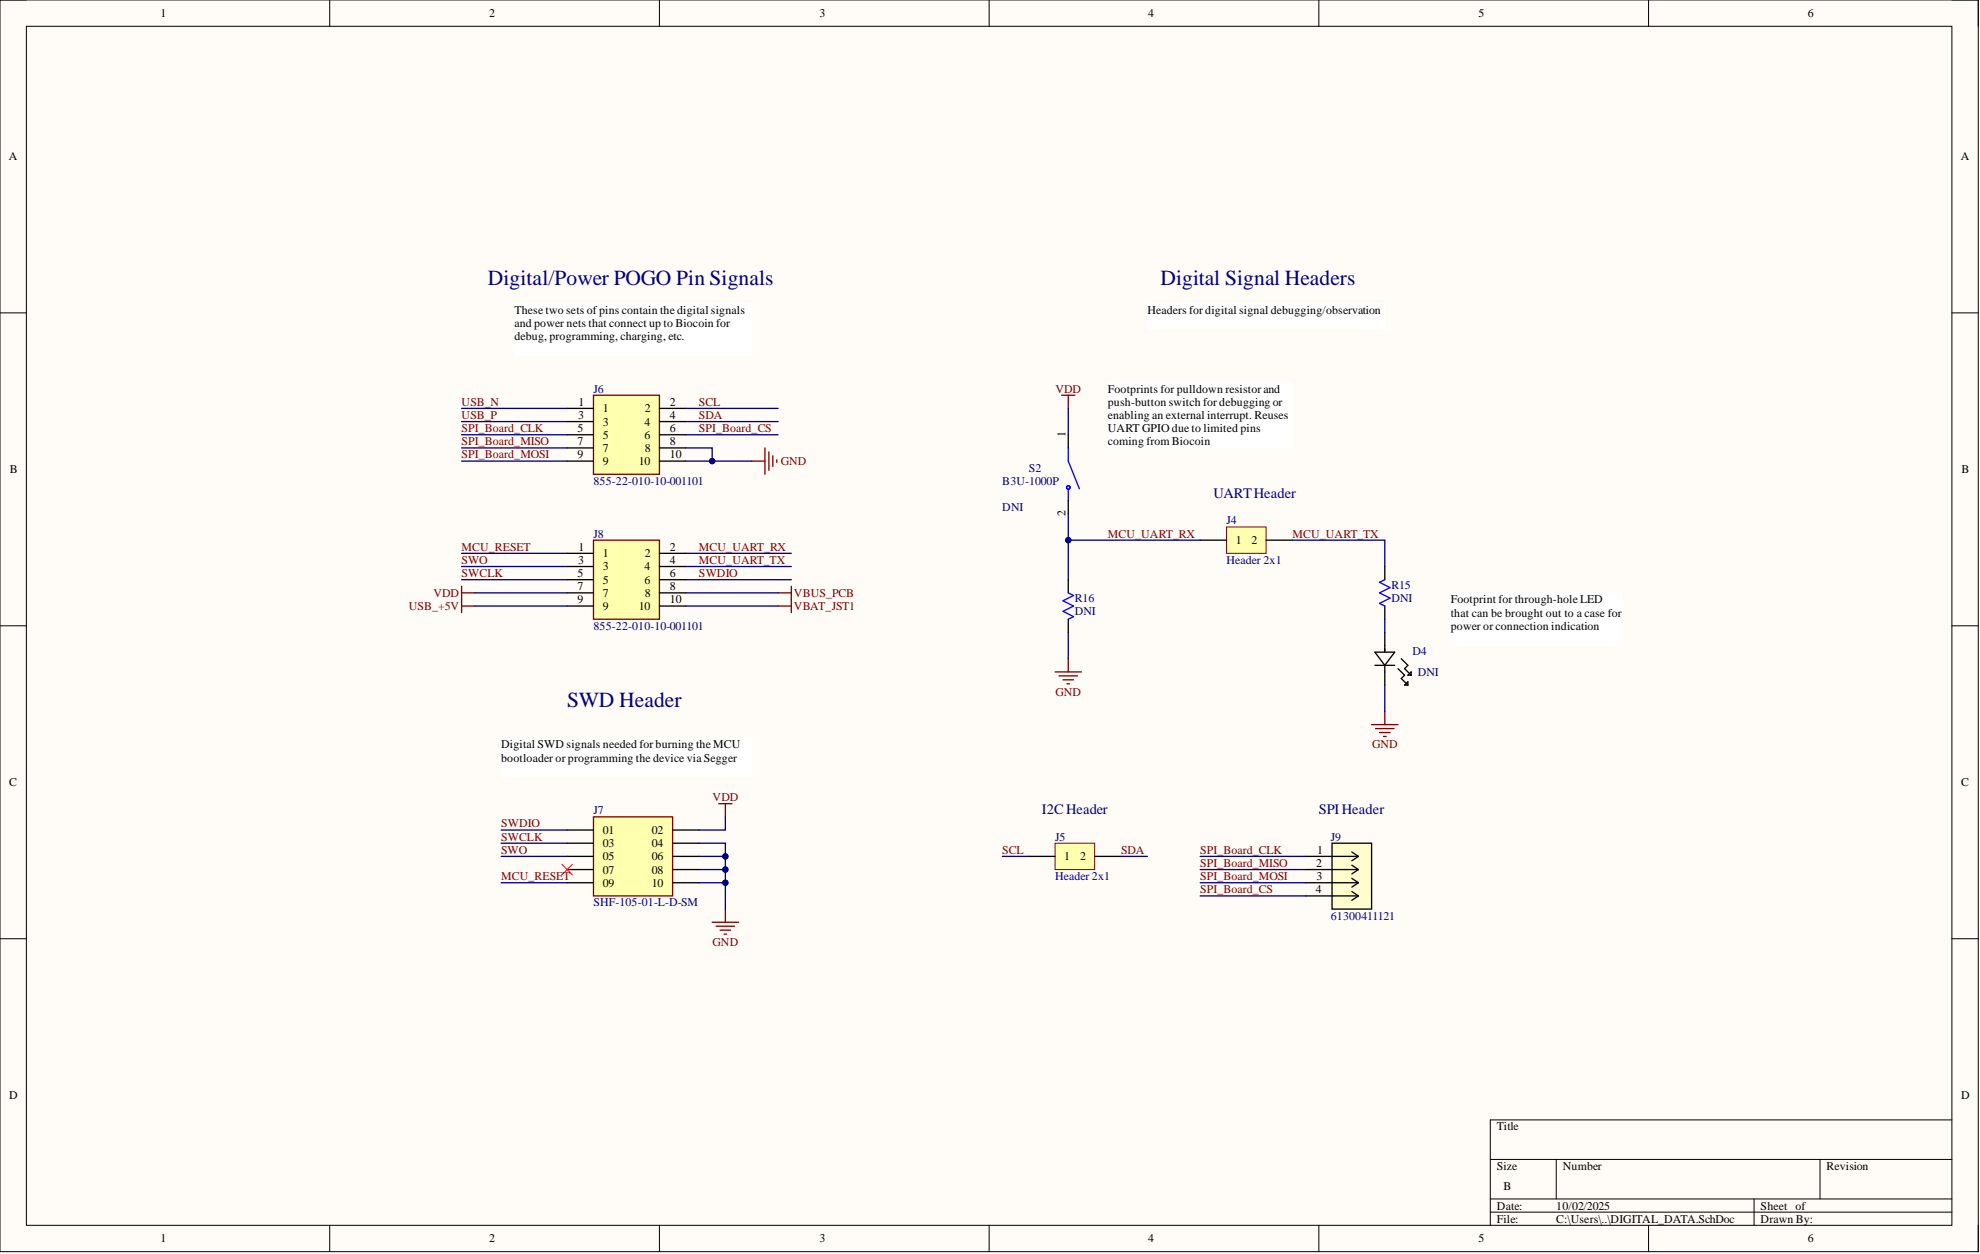
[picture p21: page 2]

Digital/Power POGO Pin Sig

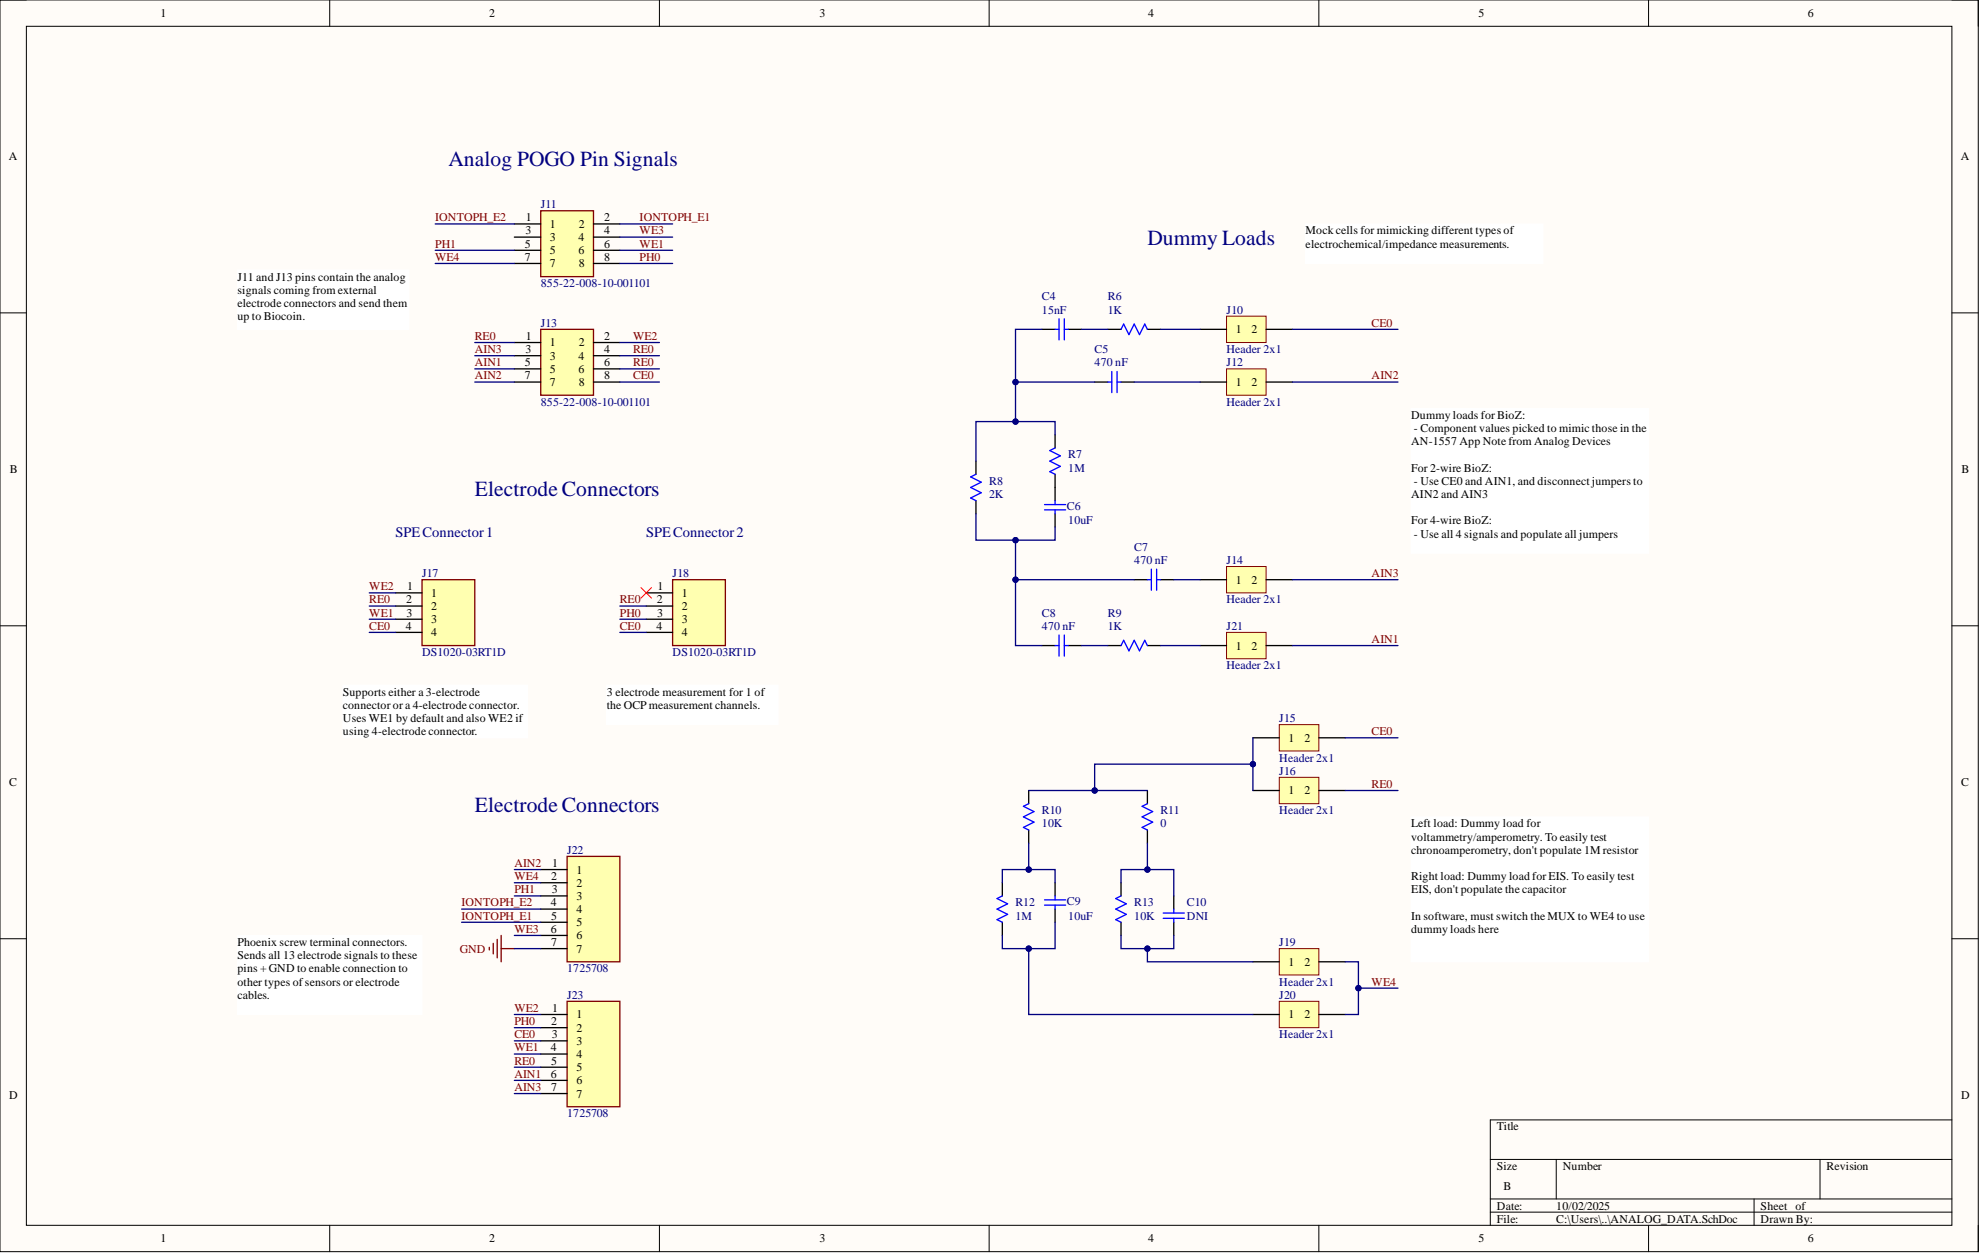
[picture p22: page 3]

Analog POGO Pin Signals

Mock cells for mimicking different types of
electrochemical/impedance measurements.

J11 and J13 pins contain the analog
signals coming from external
electrode connectors and send them
up to Biocoin.

Dummy loads for BioZ:
- Component values picked to mimic those in the
AN-1557 App Note from Analog Devices

For 2-wire BioZ:
- Use CE0 and AIN1, and disconnect jumpersto
AIN2 and AIN3

For 4-wire BioZ:
- Use all 4 signals and populate all jumpers

Supports either a 3-electrode
connector or a 4-electrode connector.
Uses WE1 by default and also WE2 if
using 4-electrode connector.

3 electrode measurement for 1 of
the OCP measurement channels.

Left load: Dummy load for
voltammetry/amperometry. To easily test
chronoamperometry, don't populate 1M resistor

Right load: Dummy load for EIS. To easily test
EIS, don't populate the capacitor

In software, must switch the MUX to WE4 to use
dummy loads here

Phoenix screw terminal connectors.
Sends all 13 electrode signals to these
pins + GND to enable connection to
other types of sensors or electrode
cables.

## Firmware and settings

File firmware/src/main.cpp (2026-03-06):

/**
 * @file main.cpp
 * @brief Firmware entry point and top-level initialization flow.
 */

//////////////////////////////////
//            Headers           //
//////////////////////////////////
#include "HWConfig/constants.h"
#include "battery/battery.h"
#include "bluetooth/bluetooth.h"
#include "power/power.h"
#include "sensors/core/sensor_manager.h"
#include "storage/storage.h"
#include "util/debug_log.h"
#include "util/util.h"

#include <Arduino.h>


//////////////////////////////////
//       Initialization         //
//////////////////////////////////
void setup() {
#ifdef DEBUG_MODE
  Serial.begin(115200); // The baudrate here does not matter when using USB CDC
  const uint32_t serialWaitStartMs = millis();
  constexpr uint32_t kSerialWaitTimeoutMs = 2000;
  while (!Serial && (millis() - serialWaitStartMs) < kSerialWaitTimeoutMs) {
    delay(10); // Wait briefly for serial in debug builds, but do not block BLE startup.
  }

  if (Serial) delay(1000); // Give the serial monitor time to attach when present.

  dbgInfo(kWelcomeMessage);
  dbgInfo("Version info:");
  dbgPrintVersion();
  dbgPrintResetReason();
#endif

  // Initialize the subsystems
  power::init();
  storage::init();
  battery::init();
  bluetooth::init();
  sensor::init();

#ifdef DEBUG_MODE
  // dbgPrintDetailedPinStatus();
  // dbgPrintInterrupts();
  dbgInfo("Done initializing... Off to sleep!");
#endif

  suspendLoop(); // This code is event driven -- it does not use the main loop
}

void loop() {}

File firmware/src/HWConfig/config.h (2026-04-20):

/**
 * @file config.h
 * @brief Project-wide firmware configuration constants and revision metadata.
 * @details Defines firmware versioning plus subsystem tuning constants used across runtime modules.
 */

#pragma once

#include <cstdint>

#define BIOCOIN_FW_VERSION "1.1.5" // Keep in sync with release tags/app compatibility.

#ifdef DEBUG_MODE
#define BIOCOIN_ENABLE_DEBUG_GATT 1
#define BIOCOIN_FW_BUILD_SUFFIX " DEBUG"
#else
#define BIOCOIN_ENABLE_DEBUG_GATT 0
#define BIOCOIN_FW_BUILD_SUFFIX ""
#endif

constexpr char kFirmwareVersion[] = BIOCOIN_FW_VERSION BIOCOIN_FW_BUILD_SUFFIX;
constexpr char kWelcomeMessage[] = "Biocoin v" BIOCOIN_FW_VERSION BIOCOIN_FW_BUILD_SUFFIX;

namespace battery {
  constexpr uint32_t kBatteryUpdateRate = 5 * 60 * 1000; // Update rate [ms] for battery voltage
  constexpr uint8_t kNumADCSamplesToAverage = 100;       // Number of samples to average per battery reading
  constexpr float kADCDividerIdeal = 4.99e6f / (4.99e6f + 10e6f);
  constexpr float kADCDividerComp = 3.00400804f; // Inverse of the divider -- measured
  // Sigmoid fit coefficients for voltage->percent mapping:
  // % = 100 / (1 + exp(-kBatteryFitSlope * (V - kBatteryFitMidVoltage)))
  constexpr float kBatteryFitSlope = 7.938f;
  constexpr float kBatteryFitMidVoltage = 3.682f;
  constexpr float kMinValidBatteryVoltageV = 2.5f;
  constexpr float kMaxValidBatteryVoltageV = 4.5f;
} // namespace battery

namespace power {
  constexpr uint32_t kBlinkOn = 50;                   // Heartbeat LED on time [ms]
  constexpr uint32_t kBlinkOff = (5 * 60 * 1000) - 50; // Heartbeat LED off time [ms]
} // namespace power

namespace bluetooth {
  // Connection/advertising defaults tuned for BLE throughput and mobile compatibility.
  constexpr int8_t kTxPower = -4;
  constexpr uint16_t kMTURequest = 247;
  constexpr float kAdvSlowRate = 200;
  constexpr float kAdvFastRate = 30;
  constexpr uint16_t kAdvFastTimeout = 30;
  constexpr float kConnectionInterval = 100;
  constexpr float kConnectionIntervalEff = 4000;
  constexpr float kSupervisorTimeout = 31000;

  constexpr char kManufacturer[] = "UCSD BioEE Group";
  constexpr char kModel[] = "Biocoin v" BIOCOIN_FW_VERSION;
  constexpr char kFirmwareRev[] = BIOCOIN_FW_VERSION BIOCOIN_FW_BUILD_SUFFIX;

  constexpr uint8_t kUUIDService[] = {0xAA, 0x93, 0xBC, 0xEA, 0x5F, 0x78, 0x23, 0x15,
                                      0xDE, 0xEF, 0x12, 0x12, 0x23, 0x15, 0x00, 0x00};

  constexpr uint8_t kUUIDChrStatus[] = {0xAA, 0x93, 0xBC, 0xEA, 0x5F, 0x78, 0x23, 0x15,
                                        0xDE, 0xEF, 0x12, 0x12, 0x24, 0x15, 0x00, 0x00};

  constexpr uint8_t kUUIDChrDeviceName[] = {0xAA, 0x93, 0xBC, 0xEA, 0x5F, 0x78, 0x23, 0x15,
                                            0xDE, 0xEF, 0x12, 0x12, 0x25, 0x15, 0x00, 0x00};
#if BIOCOIN_ENABLE_DEBUG_GATT
  constexpr uint8_t kUUIDChrDebugBattery[] = {0xAA, 0x93, 0xBC, 0xEA, 0x5F, 0x78, 0x23, 0x15,
                                               0xDE, 0xEF, 0x12, 0x12, 0x26, 0x15, 0x00, 0x00};
  constexpr uint8_t kUUIDChrDebugAFEPower[] = {0xAA, 0x93, 0xBC, 0xEA, 0x5F, 0x78, 0x23, 0x15,
                                                0xDE, 0xEF, 0x12, 0x12, 0x27, 0x15, 0x00, 0x00};
#endif

  constexpr uint8_t kUUIDChrSensorCtrl[] = {0xAA, 0x93, 0xBC, 0xEA, 0x5F, 0x78, 0x23, 0x15,
                                            0xDE, 0xEF, 0x12, 0x12, 0x28, 0x15, 0x00, 0x00};

  constexpr uint8_t kUUIDChrSensorData[] = {0xAA, 0x93, 0xBC, 0xEA, 0x5F, 0x78, 0x23, 0x15,
                                            0xDE, 0xEF, 0x12, 0x12, 0x29, 0x15, 0x00, 0x00};

  constexpr uint8_t kUUIDChrSensorParams[] = {0xAA, 0x93, 0xBC, 0xEA, 0x5F, 0x78, 0x23, 0x15,
                                              0xDE, 0xEF, 0x12, 0x12, 0x2A, 0x15, 0x00, 0x00};
} // namespace bluetooth

namespace sensor {
  constexpr float kmVperLSB = 0.14648438f;       // 2.4V ADC range and 14-bit ADC resolution = 3000mV/16384
  constexpr uint8_t kNumADCSamplesToAverage = 1; // Number of samples to average per current reading
} // namespace sensor

namespace storage {
  constexpr const char* kDefaultName = "Biocoin"; // Must be less than BLE_GAP_DEVNAME_MAX_LEN
} // namespace storage

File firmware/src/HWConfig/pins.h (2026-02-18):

/**
 * @file pins.h
 * @brief Board pin assignments and hardware signal mapping.
 * @details Centralizes GPIO mappings so hardware revisions can be managed from a single header.
 */

#pragma once

// MUX/monitoring/indicator signals
#define PIN_MUX_A0 37
#define PIN_MUX_A1 34
#define PIN_MUX_EN 35
#define PIN_VDIV 20
#define PIN_LED 28

// AFE and auxiliary GPIOs
#define PIN_AFE_GPIO1 16
#define PIN_AFE_GPIO2 17
#define PIN_AFE_GPIO3_AUX 12
#define PIN_AFE_GPIO4_AUX 5

// Iontophoresis/power-control signals
#define PIN_IONTOPH_NMOS_CTRL 10
#define PIN_IONTOPH_PMOS_CTRL 6
#define PIN_CURRENT_SENSE_OUT 21
#define PIN_BOOST_EN 13
#define PIN_BUCKBOOST_AUX_EN 8
#define PIN_BUCKBOOST_ANALOG_EN 29
#define PIN_AFE_VDD_CTRL 9
#define PIN_TEMP_VDD_CTRL 11

#define PIN_UARTRX 1

// AD5940 interface
#define PIN_AFE_IntPin_GPIO0 15
#define PIN_AFE_RESET 18
#define PIN_SPI_CS 14

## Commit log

2025-12-02 Implemented SWV technique. Fixed bug with SensorManager.
    [DPV_PCB_v2.step]
2026-02-17 Stop tracking software logs
    [DPV_PCB_v2.step]
2026-02-18 chore: harden BLE payload handling, add CI checks, and update release docs
    - Refactor BLE TX task path and fix transmit task filename typo
    - Add centralized payload validation helper and enforce length checks in GATT handlers
    - Remove stale GATT declaration and clean up sensor/task include layering
    - Normalize line endings and apply source consistency cleanups
    - Fix cleanup-introduced build issues (Sensor include, signed/unsigned compare in IMP path)
    - Add sanity/smoke/warning-gate scripts under scripts/
    - Add GitHub Actions workflow for firmware sanity + warning checks
    - Expand docs (BLE protocol, build/flash rollback, release checklist, docs index, test plan)
    - Update revision history with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
    [ad5940_hal.cpp, config.h]
2026-02-25 sensors: use ISR-compatible task notify API
2026-03-12 Added BOM cost and annotations to the schematics.
    [BOM_Final_Biocoin_v1.3_AVDD=3.0V.xlsx, BOM_Final_Biocoin_v1.3_AVDD=3.6V.xlsx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]
2026-04-18 Add PCB README
2026-04-20 Fix sensor status cleanup
    [config.h]
